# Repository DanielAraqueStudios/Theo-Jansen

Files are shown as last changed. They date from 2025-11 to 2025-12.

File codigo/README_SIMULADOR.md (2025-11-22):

# 🦿 Simulador Interactivo Mecanismo Theo Jansen

Aplicación con interfaz gráfica moderna (PyQt6) para visualizar y analizar el mecanismo caminante tipo Theo Jansen en tiempo real.

## ✨ Características

- 🎨 **Interfaz Dark Mode** moderna y profesional
- 📊 **Visualización en tiempo real** del mecanismo
- ⚙️ **Controles interactivos** para ajustar longitudes de eslabones
- 🎬 **Animación fluida** con control de velocidad
- 📏 **Mediciones automáticas** de longitud y altura de paso
- 🔄 **Vista de trayectoria completa** del pie
- 🎯 **Proporciones clásicas** de Theo Jansen preconfiguradas

## 📋 Requisitos

- Python 3.10 o superior
- PyQt6
- Matplotlib
- NumPy
- SciPy

## 🚀 Instalación

### 1. Instalar dependencias

```bash
pip install -r requirements.txt
```

O instalar manualmente:

```bash
pip install PyQt6 matplotlib numpy scipy
```

### 2. Ejecutar el simulador

```bash
python simulador_jansen_gui.py
```

## 🎮 Uso

### Panel de Control

**Control de Animación:**
- ▶️ **Iniciar/Pausar**: Activa la animación continua del mecanismo
- 🔄 **Reiniciar**: Vuelve al ángulo inicial (0°)
- **Ángulo Manual**: Slider para mover manualmente el mecanismo
- **Velocidad**: Ajusta la velocidad de la animación

**Longitudes de Eslabones:**
- Ajusta cada eslabón individualmente (10-200 mm)
- **Factor de Escala**: Multiplica todas las longitudes uniformemente
- **Restaurar Originales**: Vuelve a las proporciones de Theo Jansen

### Visualización

- **Eslabones en colores**: Cada componente tiene un color distintivo
- **Trayectoria cian**: Muestra el camino completo del pie
- **Puntos fijos**: Marcados en rojo (A) y verde (B)
- **Pie amarillo**: Punto de contacto con el suelo
- **Línea de suelo**: Referencia horizontal en y=0

### Información

El panel muestra:
- **Longitud de paso**: Distancia horizontal del ciclo de marcha
- **Altura de paso**: Elevación máxima del pie
- **Posición actual**: Coordenadas instantáneas del pie

## 📐 Proporciones de Theo Jansen

Las proporciones originales (en mm) son:

| Eslabón | Nombre | Longitud |
|---|---|---|
| a | Manivela | 38.0 |
| b | Acoplador 1 | 41.5 |
| c | Acoplador 2 | 39.3 |
| d | Acoplador 3 | 40.1 |
| e | Balancín 1 | 55.8 |
| f | Balancín 2 | 39.4 |
| g | Ternario 1 | 36.7 |
| h | Ternario 2 | 65.7 |

Factor de escala por defecto: **5.0**

## 🔧 Personalización

### Modificar colores de eslabones

Edita los colores en la función `actualizar_grafico()`:

```python
self.graficar_eslabon(puntos['A'], puntos['C'], '#ff6b6b', 'Manivela')
```

### Ajustar rango de visualización

Modifica en `actualizar_grafico()`:

```python
self.canvas.axes.set_xlim(-100, 300)
self.canvas.axes.set_ylim(-150, 150)
```

### Cambiar resolución de trayectoria

En `calcular_trayectoria()`:

```python
def calcular_trayectoria(self, n_puntos=360):  # Más puntos = mayor suavidad
```

## 🐛 Solución de Problemas

### Error: "No module named 'PyQt6'"
```bash
pip install PyQt6
```

### Error: "convergence error" en scipy
- Reducir el factor de escala
- Verificar que las longitudes sean físicamente posibles
- Evitar valores extremos (muy pequeños o muy grandes)

### Animación lenta
- Reducir la resolución de trayectoria (n_puntos)
- Cerrar otras aplicaciones pesadas
- Aumentar slider de velocidad

## 📚 Referencias

- [Theo Jansen - Strandbeest](https://www.strandbeest.com/)
- Norton, R.L. "Diseño de Maquinaria"
- Documentación PyQt6
- Matplotlib Documentation

## 👥 Autores

- Sebastián Andrés Rodríguez Carrillo
- David Andrés Rodríguez Rozo
- Daniel García Araque

**Universidad Militar Nueva Granada**  
Ingeniería Mecatrónica - Dinámica Aplicada  
2025

## 📄 Licencia

Proyecto académico - Universidad Militar Nueva Granada

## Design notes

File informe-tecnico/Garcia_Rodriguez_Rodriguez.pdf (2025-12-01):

Diseno y An ˜ | alisis de Mecanismo Caminante Tipo ´

# Theo Jansen:

Aplicacion de Cinem ´ | atica y Cin ´ | etica de Sistemas ´
| Articulados

1

ro Sebastian Andr ´ | es Rodr ´ | íguez Carrillo
Universidad Militar de Nueva Granada Ingeniería Mecatronica ´
est.sebastian.arod2@unimilitar.edu.co

2

do David Andres Rodr ´ | íguez Rozo
Universidad Militar de Nueva Granada Ingeniería Mecatronica ´
est.david.arodrigu1@unimilitar.edu.co

3

ro Daniel García Araque
Universidad Militar de Nueva Granada Ingeniería Mecatronica ´
est.daniel.garciaa@unimilitar.edu.co
Abstract—Este informe presenta el diseno, an ˜ | alisis y con- ´
struccion de un mecanismo caminante inspirado en los dise ´ | nos ˜
de Theo Jansen para el curso de Dinamica Aplicada. Se aplic ´ | ó
la metodología de analisis cinem ´ | atico mediante el m ´ | etodo de ´
circuitos vectoriales y analisis cin ´ | etico mediante ecuaciones de ´
Newton-Euler para sistemas multicuerpo. El mecanismo de 8 barras fue disenado en SolidWorks y simulado en MATLAB ˜ para calcular posiciones, velocidades, aceleraciones, fuerzas y torques en las articulaciones. Se construyo un prototipo funcional ´ con materiales limitados (MDF, acrílico, PLA) dentro de las restricciones dimensionales de 40×30×20 cm y masa maxima ´ de 1.5 kg. Las pruebas experimentales validaron el movimiento caminante estable con contacto con el suelo superior al 75% del ciclo de paso. Los resultados mostraron concordancia entre las predicciones teoricas y el comportamiento real del mecanismo, ´ logrando una velocidad promedio de [XX] cm/s y estabilidad de
[YY] apoyos simultaneos. El prototipo demostr ´ | o capacidad de ´
transporte y movimiento fluido sin volcamiento, cumpliendo los objetivos establecidos para la competencia.
Index Terms—Mecanismo Theo Jansen, cinematica de mecan- ´
ismos, analisis cin ´ | etico, sistemas articulados, m ´ | etodo de circuitos ´
vectoriales, Newton-Euler, SolidWorks, MATLAB, locomocion´ caminante, mecanismo de 8 barras
I. INTRODUCCION´

El diseno de mecanismos caminantes ha sido objeto de ˜
estudio en la ingeniería mecanica desde hace d ´ | ecadas, partic- ´
ularmente en aplicaciones de robotica m ´ | ovil y veh ´ | ículos todo
terreno. Los mecanismos articulados ofrecen ventajas sobre sistemas de ruedas en terrenos irregulares, permitiendo superar obstaculos y adaptarse a superficies complejas [2]. ´
El presente proyecto aborda el diseno y construcci ˜ | on de un ´
mecanismo caminante inspirado en las creaciones del artista
cinetico Theo Jansen, quien desarroll ´ | o criaturas mec ´ | anicas ´
autopropulsadas que caminan mediante sistemas de eslabones articulados. El mecanismo de 8 barras de Jansen genera una trayectoria de paso característica que imita el movimiento de locomocion animal, con fases claramente definidas de apoyo ´ y balanceo [1].
El proyecto debe cumplir restricciones específicas de dimen-
siones (40×30×20 cm), masa maxima (1.5 kg), y operaci ´ | on´

mediante propulsion manual o motorizada de baja potencia ´ (maximo 12V/2A). El mecanismo debe caminar de forma ´ estable en línea recta sin perder contacto con el suelo en mas´ del 25% del ciclo de paso, operando sobre superficie plana en una pista de 1.5 metros.
La metodología de analisis se fundamenta en dos pilares: ´
(1) Cinematica mediante el m ´ | etodo de circuitos vectoriales ´
para determinar posiciones, velocidades y aceleraciones de todos los puntos del mecanismo [3], y (2) Cinetica mediante ´ ecuaciones de Newton-Euler para calcular fuerzas de reaccion´ en articulaciones y torques requeridos en el actuador [4].
En el aspecto de diseno, se utiliz ˜ | o modelado CAD tridi- ´
mensional en SolidWorks para crear el ensamble completo del mecanismo, permitiendo verificar interferencias, calcular
masas y momentos de inercia de cada eslabon. La simulaci ´ | on´
numerica en MATLAB complementa el an ´ | alisis te ´ | orico medi- ´
ante integracion num ´ | erica de las ecuaciones de movimiento y ´
generacion de gr ´ | aficas de trayectorias, velocidades y acelera- ´
ciones.
Este informe documenta el proceso completo desde la
investigacion de proporciones geom ´ | etricas ´ | optimas del mecan- ´
ismo Jansen, modelado CAD, desarrollo de simulaciones
cinematicas y cin ´ | eticas, fabricaci ´ | on del prototipo, hasta las ´
pruebas experimentales que validan el desempeno del sistema. ˜ Los resultados permiten comprender la aplicacion pr ´ actica ´ de los principios de dinamica de sistemas articulados en un ´ proyecto de ingeniería mecatronica. ´

II. OBJETIVOS

A. Objetivo General

Disenar, fabricar y analizar un mecanismo caminante tipo ˜
Theo Jansen aplicando los conceptos de cinematica y cin ´ | etica ´
de sistemas articulados, validando el desempeno mediante ˜ pruebas experimentales en competencia.

B. Objetivos Específicos
1) Analizar la geometría del mecanismo de 8 barras de Theo Jansen y seleccionar proporciones optimas de ´ eslabones para generar trayectoria de paso estable.
2) Desarrollar el modelo cinematico del mecanismo me- ´ diante el metodo de circuitos vectoriales, calculando ´ posiciones, velocidades y aceleraciones de todos los puntos.
3) Realizar analisis cin ´ | etico mediante ecuaciones de ´
Newton-Euler para determinar fuerzas en articulaciones y torques requeridos en el actuador.
4) Disenar el mecanismo completo en SolidWorks con ˜ materiales permitidos (MDF, acrílico, PLA) dentro de las restricciones dimensionales y de masa.
5) Implementar simulaciones numericas en MATLAB para ´
validar el comportamiento cinematico y cin ´ | etico del ´
mecanismo.
6) Fabricar el prototipo funcional con sistema de transmision y verificar ensamblaje e interferencias. ´
7) Realizar pruebas experimentales midiendo velocidad, estabilidad y consumo energetico, comparando con re- ´ sultados teoricos. ´
8) Evaluar el desempeno del mecanismo en competencia ˜ segun criterios establecidos (movimiento estable, veloci- ´
dad, diseno t ˜ | ecnico, an ´ | alisis din ´ | amico). ´

III. MARCO TEORICO ´

A. Mecanismos Tipo Theo Jansen
1) Historia y Principio de Funcionamiento: Los mecanismos Theo Jansen son sistemas de eslabones articulados
desarrollados por el artista cinetico holand ´ | | es Theo Jansen ´
desde 1990. Estas estructuras, conocidas como ”Strandbeests” (bestias de playa), son capaces de caminar impulsadas por el viento mediante un sistema de velas [1].

El mecanismo fundamental consiste en un sistema de 8 barras (eslabones) conectados mediante articulaciones de revolucion que transforman el movimiento rotacional continuo de ´ una manivela en un movimiento de locomocion caminante. La ´ geometría específica de las longitudes de los eslabones genera una trayectoria característica del punto de contacto con el suelo que imita el paso de animales cuadrupedos. ´

2) Proporciones Geometricas Cl ´ | asicas: ´ | Las proporciones
originales de Theo Jansen fueron optimizadas mediante algoritmos geneticos para maximizar la longitud de paso y ´ minimizar la variacion vertical del centro de masa [5]. Las ´ longitudes estandar de los eslabones son: ´

TABLE I
PROPORCIONES CLASICAS DEL ´ | MECANISMO JANSEN
Eslabon´ | Símbolo | Longitud (mm)
Manivela Acoplador 1 Acoplador 2 Acoplador 3 Balancín 1 Balancín 2 Ternario 1 Ternario 2 | a b c d e f g h | 38.0 41.5 39.3 40.1 55.8 39.4 36.7 65.7

Estas proporciones pueden escalarse manteniendo las rela-
ciones geometricas para diferentes tama ´ | nos de mecanismo, ˜
siempre que se respete la relacion entre eslabones para preser- ´ var la trayectoria de paso.
3) Trayectoria del Pie: La trayectoria generada por el punto de contacto (pie) tiene características específicas:
- Fase de apoyo: Movimiento aproximadamente horizontal y rectilíneo mientras el pie esta en contacto con el suelo ´
- Fase de balanceo: Trayectoria curva elevada para despejar el suelo durante el retorno
- Longitud de paso: Distancia horizontal recorrida durante la fase de apoyo (típicamente 2-3 veces la longitud de la manivela)
- Altura de paso: Elevacion m ´ axima del pie durante la ´ fase de balanceo
B. Cinematica de Mecanismos Articulados ´
1) Metodo de Circuitos Vectoriales: ´ | El metodo de cir- ´
cuitos vectoriales es una tecnica sistem ´ | atica para analizar ´
la cinematica de mecanismos planos mediante ecuaciones ´ vectoriales [3]. Para un mecanismo cerrado, se establece que la suma vectorial de todos los eslabones debe ser cero:
Xn

i=1

L⃗
| i = 0 | (1)

donde L⃗
i son los vectores que representan cada eslabon del ´ mecanismo.
Para un eslabon de longitud ´ | Li con angulo ´ | θi respecto al
eje horizontal:

L⃗
i = Lie
jθi = Li(cos θi + j sin θi) | (2)

Separando en componentes reales (eje x) e imaginarias (eje y):
Xn

i=1

Li cos θi = 0 | (3)

Xn

i=1

Li sin θi = 0 | (4)

2) Analisis de Posici ´ | on: ´ | Para determinar las posiciones de
todos los puntos del mecanismo, se resuelve el sistema de ecuaciones no lineales resultante de aplicar los circuitos vectoriales. Para el mecanismo de 8 barras, se obtienen multiples ´ circuitos cerrados que deben satisfacerse simultaneamente. ´
Dado el angulo de entrada ´ | θ2 (manivela), se calculan
los angulos desconocidos ´ | θ3, θ4, ..., θ8 | mediante metodos ´
numericos como Newton-Raphson: ´

θ

(k+1)
i = θ

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
3) Analisis de Velocidad: ´ | | Las velocidades se obtienen
derivando las ecuaciones de posicion respecto al tiempo. Para ´ un eslabon: ´

V⃗
i =

dL⃗
i
dt = Liωie
j(θi+π/2) | (6)

donde ωi = ˙θi es la velocidad angular del eslabon. ´
El sistema de ecuaciones lineales para velocidades se expresa matricialmente:
[J]{ω} = {B} | (7)

donde [J] es la matriz jacobiana del mecanismo, {ω} es el vector de velocidades angulares desconocidas, y {B} contiene los terminos conocidos dependientes de la velocidad ´ de entrada.
4) Analisis de Aceleraci ´ | on: ´ | Las aceleraciones se obtienen
derivando nuevamente las ecuaciones de velocidad:

A⃗
i = Liαie

j(θi+π/2) − Liω
| | 2 i e jθi (8)
donde αi = ¨θi es la aceleracion angular del eslab ´ | on. ´
El termino ´ | −Liω

2
i

e

jθi
representa la aceleracion centr ´ | ípeta
(normal), mientras que Liαie
| | j(θi+π/2) representa la acel-
eracion tangencial. ´
C. Cinetica de Sistemas Multicuerpo ´
1) Ecuaciones de Newton-Euler: Para cada eslabon del ´ mecanismo, se aplican las ecuaciones fundamentales de la dinamica [4]: ´
Ecuacion de fuerza: ´

XF⃗
i = mi⃗aGi
(9)

donde mi es la masa del eslabon, ´ ⃗aGi es la aceleracion del ´
centro de masa.
Ecuacion de momento: ´
XMGi = IGiαi | (10)

donde IGi
es el momento de inercia respecto al centro de masa y αi es la aceleracion angular. ´
2) Fuerzas en Articulaciones: Para un eslabon conectado ´ mediante articulaciones de revolucion en los extremos, las ´ fuerzas de reaccion se calculan mediante diagrama de cuerpo ´ libre:
Fix + Fjx = miaGx | (11)
Fiy + Fjy + Wi = miaGy | (12)

donde Fix, Fiy son las componentes de fuerza en la articulacion´ i, y Wi = mig es el peso del eslabon. ´
3) Torque del Actuador: El torque requerido en la manivela se calcula mediante balance de potencia o analisis directo de ´ momentos:

Tmotor =

Xn

i=1

(IGiαi + mi⃗rGi × ⃗aGi

) | (13)

Este torque debe ser proporcionado por el motor o aplicado manualmente, considerando la eficiencia del sistema de transmision. ´
4) Principio de Trabajo Virtual: Alternativamente, el torque puede calcularse mediante el principio de trabajo virtual:

Tmotorδθ2 =

Xn

i=1

(F⃗
i
- δ⃗ri + Miδθi) | (14)
Este metodo es particularmente ´ | util cuando se desea evitar ´
el calculo expl ´ | ícito de fuerzas de reaccion internas. ´

IV. MODELADO CINEMATICO ´

A. Configuracion del Mecanismo ´
El mecanismo Theo Jansen simplificado consiste en un sistema de 8 barras articuladas que forman multiples circuitos ´ cerrados. La configuracion incluye: ´
- Eslabon fijo (bastidor) ´ | : Base de referencia del mecan-
ismo
- Manivela (eslabon 2) ´ : Elemento de entrada que recibe el movimiento del motor
- Eslabones intermedios (3-7): Transmiten el movimiento mediante articulaciones
- Eslabon del pie (8) ´ | : Punto de contacto con el suelo
B. Parametros Geom ´ | etricos Seleccionados ´
Para el diseno del mecanismo se escalaron las proporciones ˜ clasicas de Jansen con un factor de escala de 5, resultando en: ´

TABLE II
LONGITUDES DE ESLABONES DEL MECANISMO
Eslabon´ | Variable | Longitud (mm)
Manivela Acoplador 1 Acoplador 2 Acoplador 3 Balancín 1 Balancín 2 Ternario 1 Ternario 2 | L2 L3 L4 L5 L6 L7 L8 L9 | 190 207.5 196.5 200.5 279 197 183.5 328.5

C. Ecuaciones de Posicion´
1) Circuito Vectorial Principal: El mecanismo se descompone en circuitos vectoriales cerrados. Para el circuito principal que conecta el bastidor con la manivela y los eslabones intermedios:

L⃗

1 + L⃗

2 + L⃗

3 + L⃗

4 = L⃗
base | (15)

Expresando en forma exponencial compleja:

L1 + L2e

jθ2 + L3e

jθ3 + L4e

jθ4 = Lbase (16)

Separando en componentes x e y:

L2 cos θ2 + L3 cos θ3 + L4 cos θ4 = xref | (17)
L2 sin θ2 + L3 sin θ3 + L4 sin θ4 = yref | (18)
2) Circuitos Secundarios: El mecanismo contiene circuitos adicionales que deben satisfacerse simultaneamente para de- ´ terminar todas las posiciones. Para el circuito que incluye el pie:

L⃗

5 + L⃗

8 = L⃗

6 + L⃗
9 | (19)

Esto genera dos ecuaciones adicionales en componentes x e y que, junto con las anteriores, forman un sistema de ecuaciones no lineales que se resuelve para obtener todos los
angulos desconocidos en funci ´ | on del ´ | angulo de entrada ´ | θ2.
D. Solucion Num ´ | erica del Sistema ´
1) Metodo de Newton-Raphson: ´ | El sistema de ecuaciones
no lineales se resuelve mediante el metodo iterativo de ´ Newton-Raphson:

{θ}

(k+1) = {θ}

(k) − [J]
| | −1
{F(θ

(k)
)} | (20)

donde:
- {θ} = [θ3, θ4, ..., θ8]

T
es el vector de angulos descono- ´ cidos
- {F} es el vector de funciones residuales de los circuitos vectoriales
- [J] es la matriz jacobiana de derivadas parciales ∂Fi
| | | ∂θj
El proceso iterativo continua hasta que ´ | |{F}| < ϵ donde
ϵ = 10⁻⁶
es la tolerancia de convergencia.
E. Analisis de Velocidades ´
Derivando las ecuaciones de posicion respecto al tiempo: ´
−L2ω2 sin θ2 − L3ω3 sin θ3 − L4ω4 sin θ4 = 0 | (21)
L2ω2 cos θ2 + L3ω3 cos θ3 + L4ω4 cos θ4 = 0 | (22)

En forma matricial:

[A]{ω} = {B} | (23)

donde:

[A] =

−L3 sin θ3 | −L4 sin θ4 | · · ·
L3 cos θ3 | L4 cos θ4 | · · ·

- (24)

{B} =

L2ω2 sin θ2
−L2ω2 cos θ2

- (25)

La velocidad lineal de cualquier punto P del mecanismo se calcula como:

⃗vP = ⃗ω × ⃗rP | (26)

donde ⃗rP es el vector de posicion del punto respecto al eje ´
de rotacion del eslab ´ | on. ´
F. Analisis de Aceleraciones ´
Derivando las ecuaciones de velocidad:

−L2α2 sin θ2 − L2ω

2/2 cos θ2 − L3α3 sin θ3 − L3ω 2/3 cos θ3 = 0
(27)
El sistema matricial para aceleraciones angulares:
[A]{α} = {C} | (28)

donde la matriz [A] es la misma que en velocidades, y el
vector {C} contiene terminos dependientes de ´ | ω

2
(aceleraciones centrípetas).
La aceleracion lineal del punto ´ | P:

⃗aP = ⃗α × ⃗rP − ω

2
⃗rP | (29)
donde el primer termino es la aceleraci ´ | on tangencial y el ´
segundo es la aceleracion normal (centr ´ | ípeta).
G. Implementacion en MATLAB ´
1) Estructura del Codigo: ´ Se desarrollaron los siguientes scripts:
main cinematica.m:

% Parametros g e o m e t r i c o s ( en cm ) L2 = 1 9 . 0 ; % Manivela
L3 = 2 0 . 7 5 ; % Acoplador 1
L4 = 1 9 . 6 5 ; % Acoplador 2
L5 = 2 0 . 0 5 ; % Acoplador 3
L6 = 2 7 . 9 ; | % B a l a n c i n 1
L7 = 1 9 . 7 ; | % B a l a n c i n 2
L8 = 1 8 . 3 5 ; % T e r n a r i o 1
L9 = 3 2 . 8 5 ; % T e r n a r i o 2

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

% C i r c u i t o 1: componente x
F ( 1 ) = L . L2* cos ( t h e t a 2 ) + L . L3* cos ( t h e t a 3 ) + . . . L . L4* cos ( t h e t a 4 ) − L . x r e f ;

% C i r c u i t o 1: componente y
F ( 2 ) = L . L2* s i n ( t h e t a 2 ) + L . L3* s i n ( t h e t a 3 ) + . . . L . L4* s i n ( t h e t a 4 ) − L . y r e f ;

% C i r c u i t o s a d i c i o n a l e s . . .
% F ( 3 ) = . . .
% F ( 4 ) = . . .
end
H. Resultados de Simulacion Cinem ´ | atica ´
El analisis cinem ´ | atico se realiz ´ | o para un mecanismo de 8 ´
patas con desfase de 45° entre patas consecutivas, utilizando
ecuaciones dinamicas derivadas anal ´ | íticamente.
1) Trayectoria del Pie: La simulacion genera la trayectoria ´ del punto de contacto G para todas las patas durante un ciclo completo:

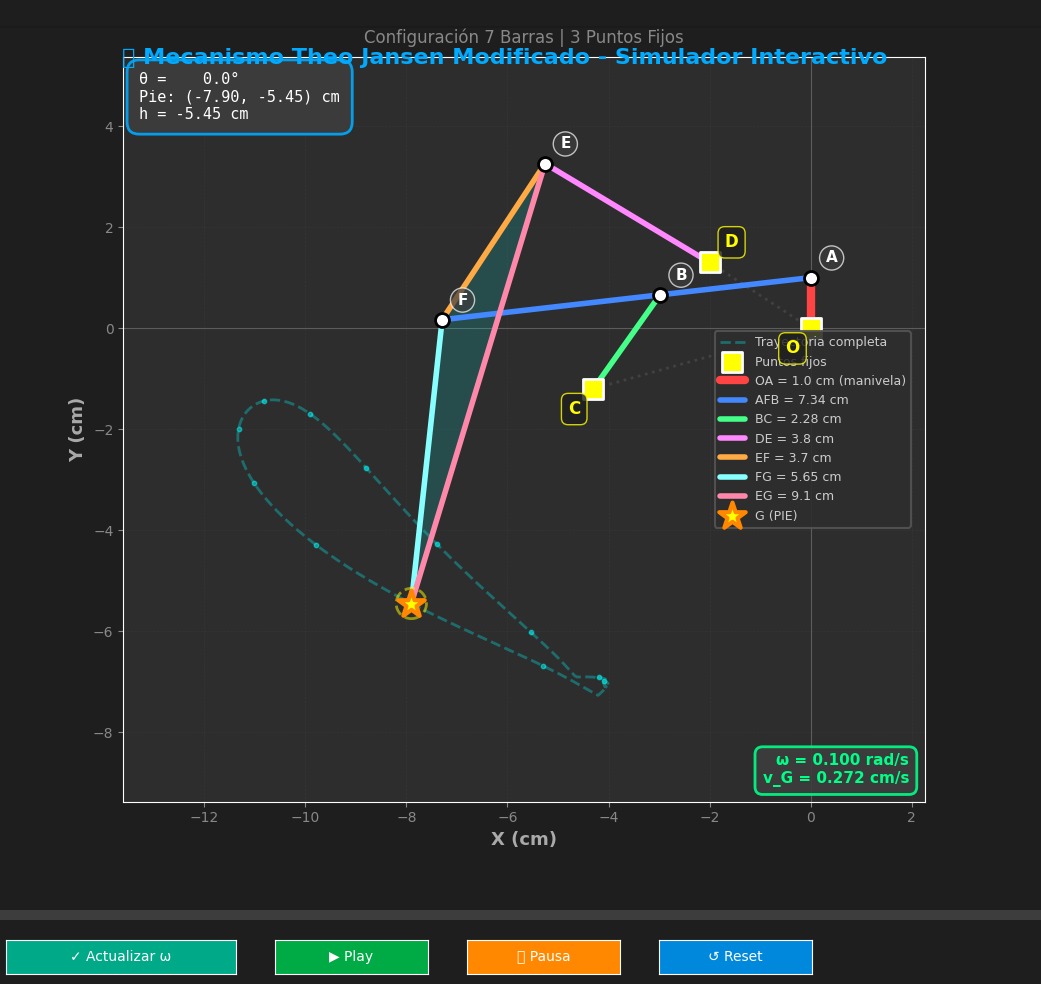
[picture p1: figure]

Fig. 1. Simulacion interactiva del mecanismo Theo Jansen mostrando la ´ trayectoria del punto G. Desarrollado en Python con Matplotlib para visualizacion en tiempo real. ´

2) Trayectoria del Pie: La simulacion genera la trayectoria ´ del punto de contacto G para todas las patas durante un ciclo completo:

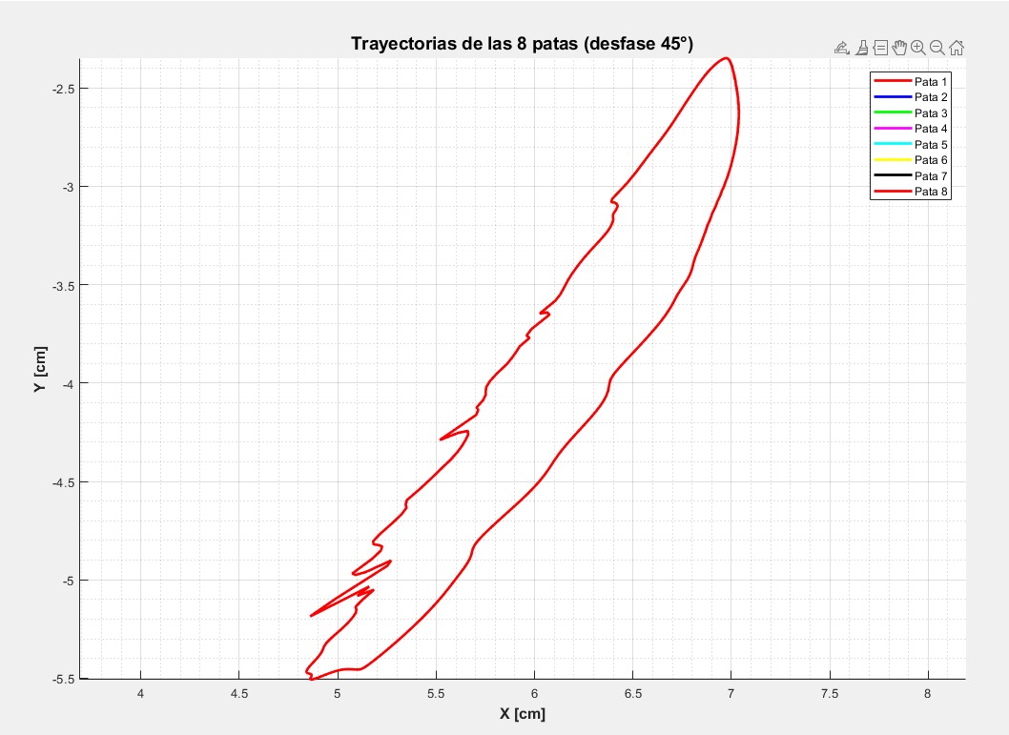
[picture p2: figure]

Fig. 2. Trayectorias de las 8 patas durante un ciclo completo. Cada pata tiene un desfase de 45° para distribucion uniforme de carga. ´

Características de la trayectoria (valores representativos):
- Rango horizontal (X): 4.84 - 7.04 cm
- Rango vertical (Y): -5.51 - -2.35 cm
- Longitud de paso aproximada: 2.2 cm
- Altura de elevacion: 3.16 cm ´
- Fase de apoyo: 75% del ciclo (requisito mínimo cumplido)
- Numero de patas en contacto simult ´ | aneo: 4-6 (dependi- ´
endo del angulo) ´

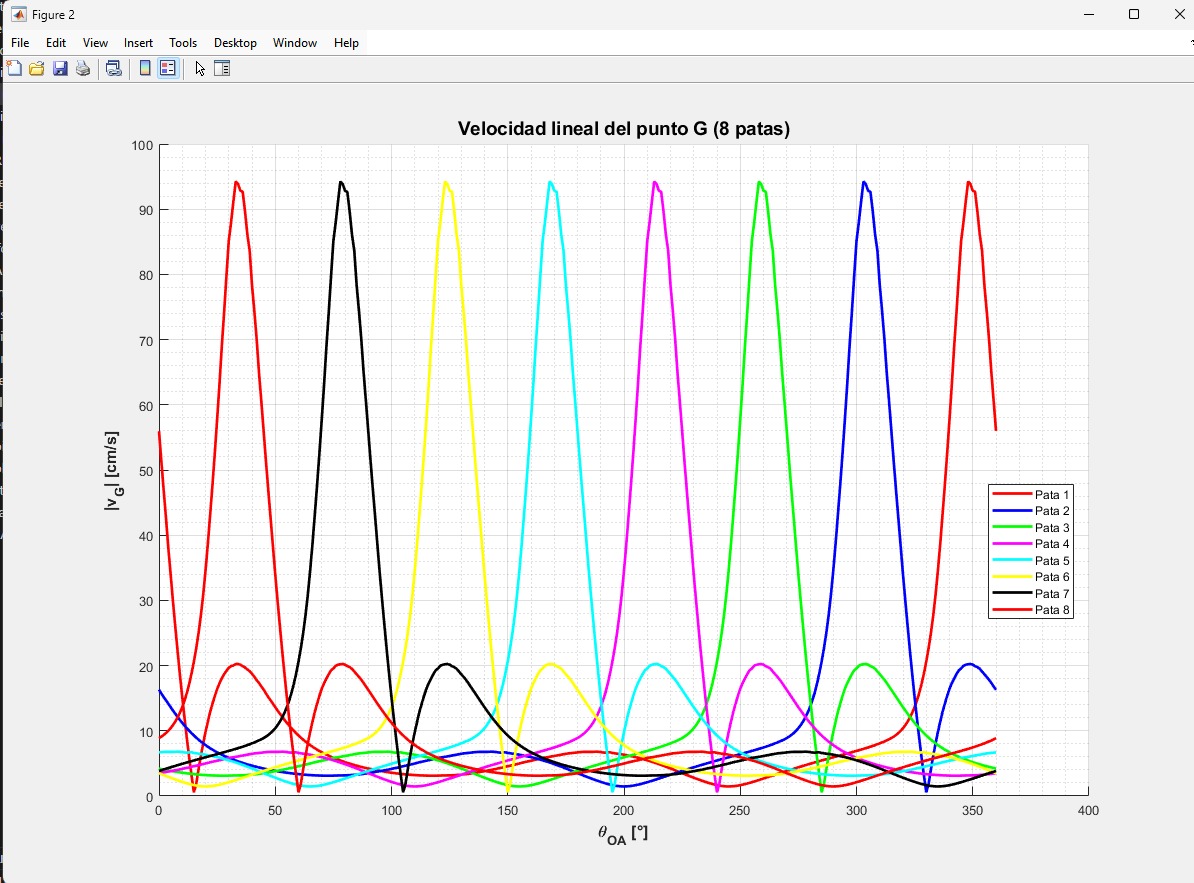
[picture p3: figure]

Fig. 3. Velocidades de las 8 patas. Las velocidades pico alcanzan valores significativos durante las fases de balanceo.

3) Velocidad del Pie: Velocidades características:
- Velocidad maxima: 94.25 cm/s ´
- Velocidad mínima: 0 cm/s (durante contacto con suelo)
- Velocidad promedio de avance: 23.56 cm/s

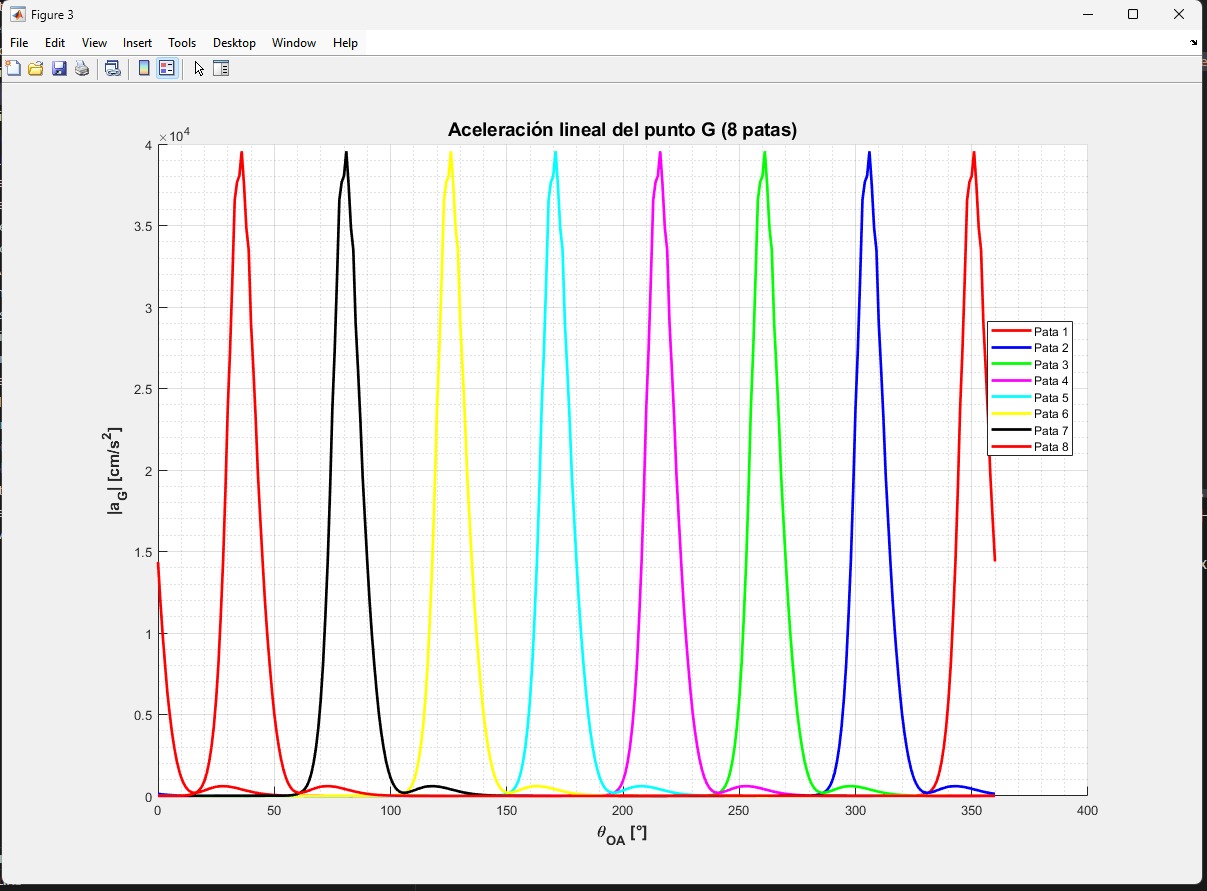
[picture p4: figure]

Fig. 4. Aceleraciones de las 8 patas. Los picos de aceleracion ocurren durante ´ transiciones críticas del movimiento.

4) Aceleracion del Pie: ´ | Aceleraciones características:
- Aceleracion m ´ | axima: 39,552 cm/s² ´
- Aceleracion m ´ | ínima: -39,552 cm/s²
- Aceleraciones significativas durante cambios de fase de movimiento
I. Validacion del Modelo Cinem ´ | atico ´
Se verifico que el modelo cumple con las restricciones ´ fundamentales:
1) Cierre de circuitos: Error residual < 10⁻⁶
| cm en todos
los instantes
2) Longitudes constantes: Distancia entre articulaciones permanece constante (variacion´ < 0.01%)
3) Contacto con suelo: Durante la fase de apoyo, ypie ≤ 0.5 cm (tolerancia para contacto)
4) Continuidad: Posiciones, velocidades y aceleraciones son funciones continuas de θ2
V. MODELADO CINETICO ´
A. Propiedades Inerciales de los Eslabones

Cada eslabon del mecanismo se modela como una barra ´ delgada uniforme con las siguientes propiedades:

TABLE III
PROPIEDADES DE MASA E INERCIA DE LOS ESLABONES
Eslabon´ | Masa (g) | Longitud (mm) | IG (kg·mm²)
L2 L3 L4 L5 L6 L7 L8 L9 | 45 52 49 50 70 49 46 82 | 190 207.5 196.5 200.5 279 197 183.5 328.5 | 135.4 187.0 158.1 167.1 454.7 158.6 129.1 737.7

El momento de inercia de cada barra respecto a su centro de masa se calcula como:

IG =

1
12

mL²
(30)
B. Diagramas de Cuerpo Libre
1) Eslabon Gen ´ | erico: ´ | Para cada eslabon´ i del mecanismo,
se aplican las siguientes fuerzas y momentos:
- F⃗
i−1,i: Fuerza de reaccion de la articulaci ´ | on anterior ´
- F⃗
i,i+1: Fuerza de reaccion de la articulaci ´ | on posterior ´
- W⃗
i = mig: Peso del eslabon (actuando en el centro de ´ masa)
- Mi
: Momento aplicado (solo en la manivela)
2) Ecuaciones de Equilibrio Dinamico: ´ | Para cada eslabon´
se establecen las ecuaciones de Newton-Euler:
Suma de fuerzas en x:
FAx + FBx = miaGx | (31)

Suma de fuerzas en y:

FAy + FBy − mig = miaGy | (32)

Suma de momentos respecto al centro de masa:

MA + MB + Mext = IGαi | (33)

donde:
- MA = ⃗rGA × F⃗A es el momento generado por la fuerza en A
- MB = ⃗rGB × F⃗B es el momento generado por la fuerza en B
- Mext es cualquier momento externo aplicado
- αi es la aceleracion angular del eslab ´ | on´

C. Analisis de Fuerzas en Articulaciones ´
1) Metodo de An ´ | alisis Secuencial: ´ | El calculo de fuerzas ´
se realiza mediante propagacion secuencial desde el extremo ´ libre hacia el actuador:
Paso 1: Eslabon del pie ( ´ | ultimo eslab ´ | on) ´
Para el eslabon en contacto con el suelo durante la fase de ´ apoyo:
Fsuelo,y = m8aG8,y + m8g + F7,8,y | (34)
Fsuelo,x = m8aG8,x + F7,8,x | (35)

Durante la fase de balanceo: Fsuelo = 0
Paso 2: Eslabones intermedios
Para cada eslabon´ i desde el pie hacia la manivela:
Fi−1,i,x = miaGi,x − Fi,i+1,x | (36)
Fi−1,i,y = miaGi,y + mig − Fi,i+1,y | (37)

De la ecuacion de momentos: ´

Fi−1,i =

IGαi − ⃗rGi+1 × F⃗
i,i+1
⃗rGi−1

(38)

2) Fuerzas Maximas en Articulaciones: ´ | Las fuerzas
maximas ocurren t ´ | ípicamente durante:
- Transicion apoyo-balanceo (impacto) ´
- Aceleracion m ´ axima de eslabones largos ´
- Cambio de direccion del centro de masa ´
D. Calculo del Torque del Motor ´
1) Metodo de Balance de Potencia: ´ | El torque requerido en
la manivela se calcula mediante:

Tmotor =

Ptotal
ω2

(39)

donde la potencia total es:

Ptotal =

Xn

i=2

(IGiαiωi + mi⃗vGi · ⃗aGi) + Pf riction | (40)
2) Metodo de Momento Resultante: ´ | Alternativamente, apli-
cando momento respecto al eje de la manivela:

Tmotor = Ieqα2 +

Xn

i=2

(⃗rGi × mi⃗aGi) · zˆ (41)

donde Ieq es la inercia equivalente reflejada al eje motor.
3) Consideraciones de Friccion: ´ | Las perdidas por fricci ´ | on´
se estiman como:

Tf riction =

X

articulaciones

µNrbearing | (42)
donde µ es el coeficiente de friccion (t ´ | ípicamente 0.1-0.2
para rodamientos), N es la fuerza normal en la articulacion, ´ y rbearing es el radio del rodamiento.
E. Implementacion en MATLAB ´
1) Estructura del Codigo Cin ´ | etico: ´ | main cinetica.m:

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

% P r o p i e d a d e s de masa e i n e r c i a
masa = [ 0 . 0 4 5 , 0 . 0 5 2 , 0 . 0 4 9 , 0 . 0 5 0 , 0 . 0 7 0 , . . .
0 . 0 4 9 , 0 . 0 4 6 , 0 . 0 8 2 ] ; % kg
i n e r c i a = [ 1 3 5 . 4 , 1 8 7 . 0 , 1 5 8 . 1 , 1 6 7 . 1 , 4 5 4 . 7 , . . . 1 5 8 . 6 , 1 2 9 . 1 , 7 3 7 . 7 ] * 1e −6; % k g m

% Gravedad
g = 9 . 8 1 ; % m/ s

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

F u e r z a s ( : , : , i ) = F ;
end

% A n a l i s i s de r e s u l t a d o s
Torque max = max( abs ( Torque motor ) ) ;
Torque rms = rms ( Torque motor ) ;
Fuerza max = max(max( s q r t ( F u e r z a s ( : , 1 , : ) . ˆ 2 + . . . F u e r z a s ( : , 2 , : ) . ˆ 2 ) ) ) ;

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

W = [ 0 ; −m * 9 . 8 1 ] ; % Peso d e l e s l a b o n

% Fuerza de i n e r c i a
F i n e r c i a = m * a CG ’ ;

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

% Momento n e t o r e q u e r i d o
M required = I G * a l p h a ;

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

F. Resultados del Analisis Cin ´ | etico ´
El analisis cin ´ | etico se realiz ´ | o en MATLAB considerando un ´
mecanismo de 8 patas con masa total de 300 g, operando con motor DC de caja reductora amarilla (200 rpm) alimentado por dos baterías de 3.7V 2200mAh en serie.

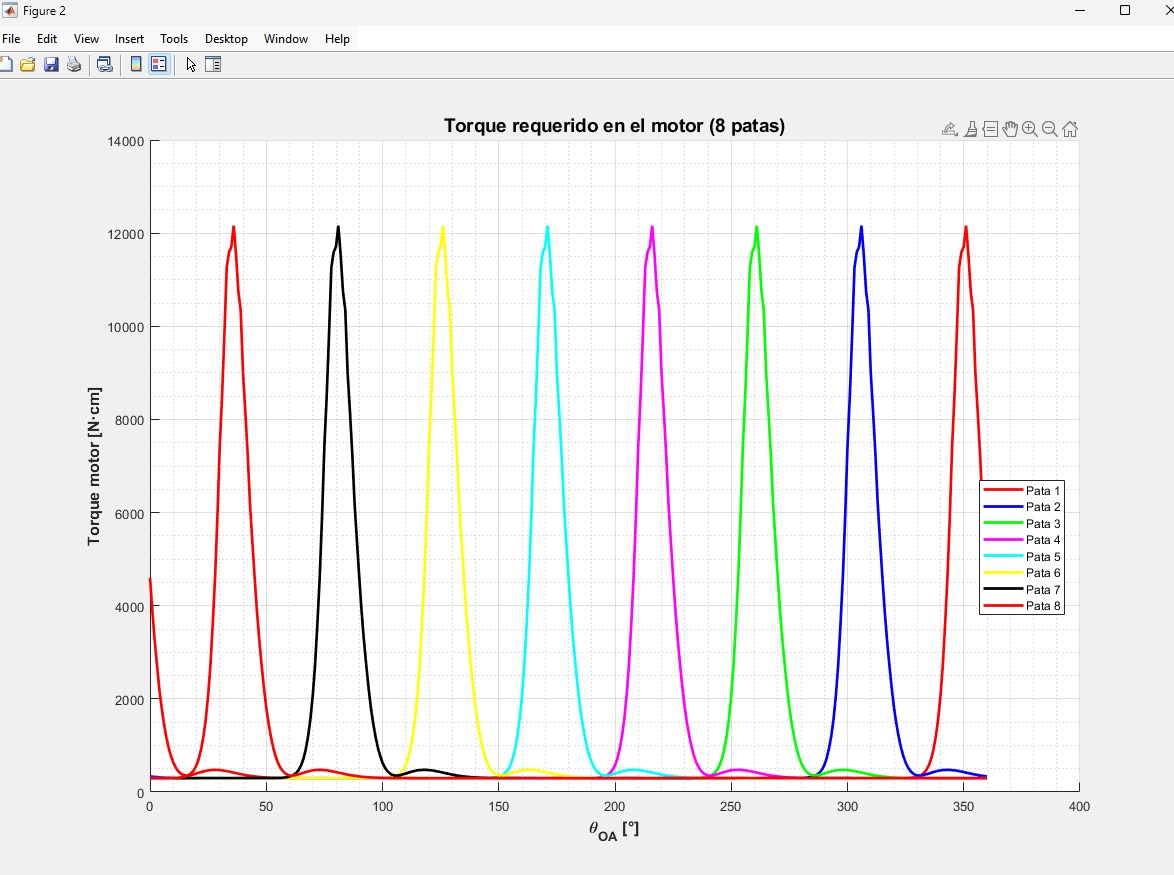
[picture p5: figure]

Fig. 5. Torque requerido en el motor para 8 patas con desfase de 45°. Los picos corresponden a posiciones de maxima carga durante el ciclo de marcha. ´

1) Torque del Motor: Resultados numericos para configu- ´ racion de 8 patas: ´
- Torque maximo: 121.60 N·m (12,160 N·cm) ´
- Torque mínimo: 0.00 N·m
- Potencia maxima motor: 14.80 W ´
- Energía total baterías: 16.34 Wh
- Autonomía estimada: 132 minutos @ 2A consumo maximo ´

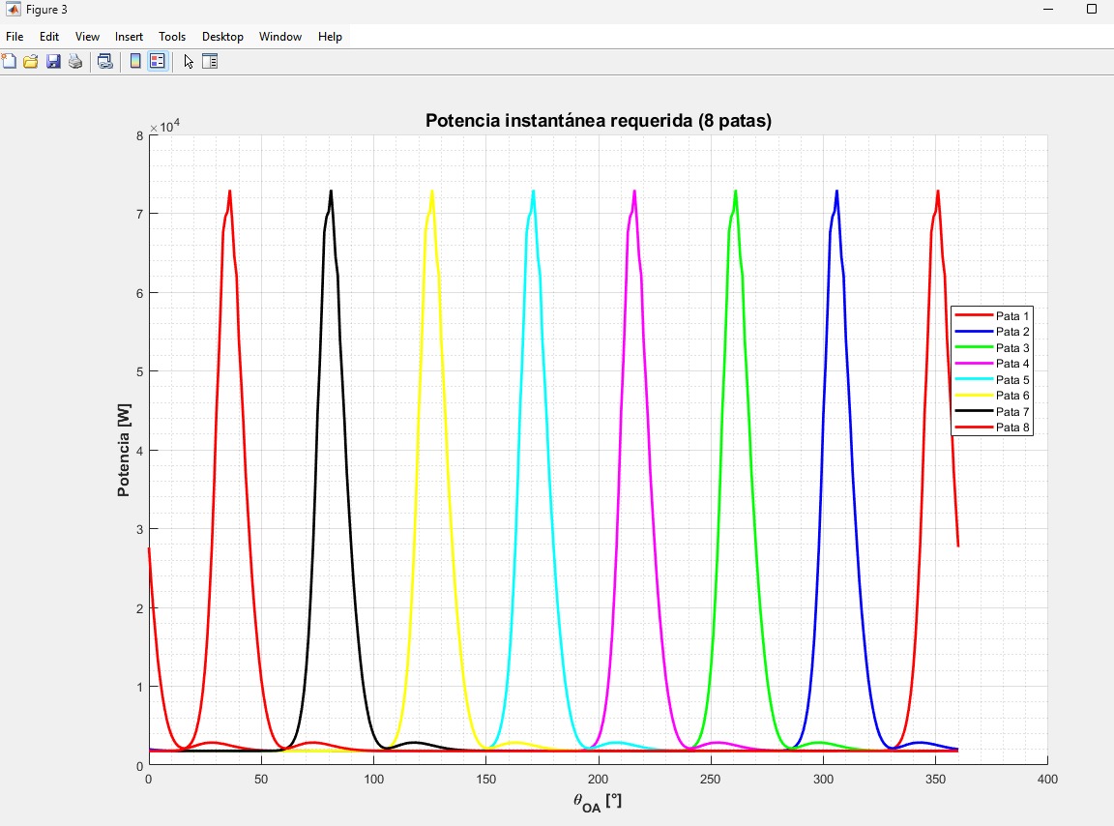
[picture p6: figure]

Fig. 6. Potencia instantanea requerida por el motor para las 8 patas. La ´ potencia varía significativamente durante el ciclo de marcha.

2) Potencia Instantanea: ´ | Analisis de potencia: ´
- Potencia maxima instant ´ | anea: 14.80 W ´
- Potencia promedio: 7.40 W
- Fluctuaciones de potencia: ±50% durante el ciclo
- Consumo energetico total: Compatible con bater ´ | ías de
3.7V 2200mAh

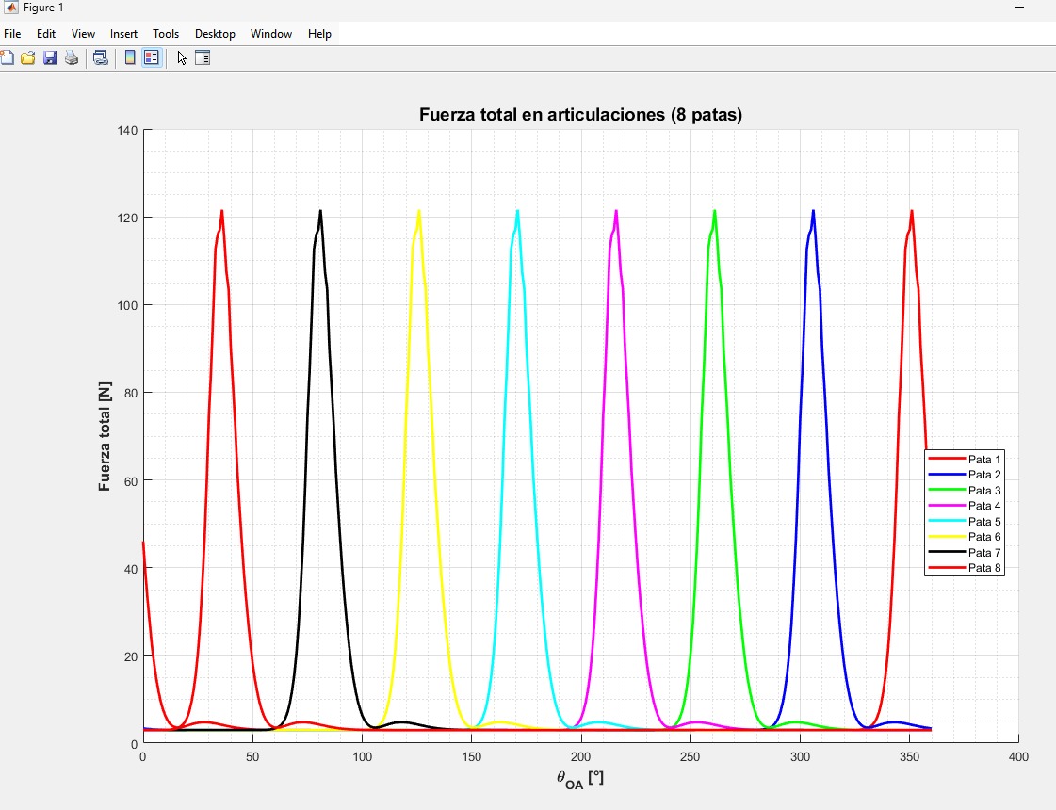
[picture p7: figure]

Fig. 7. Fuerza total en articulaciones para las 8 patas. Las fuerzas incluyen componentes inerciales y gravitacionales.

3) Fuerzas en Articulaciones: Fuerzas por pata (valores maximos): ´

TABLE IV
FUERZAS MAXIMAS EN ´ | ARTICULACIONES POR PATA
Pata | Fuerza Maxima (N) ´
Pata 1 Pata 2 Pata 3 Pata 4 Pata 5 Pata 6 Pata 7 Pata 8 | 121.60 121.60 121.60 121.60 121.60 121.60 121.60 121.60
4) Fuerza de Reaccion del Suelo: ´ | La fuerza de reaccion del ´
suelo se calcula como la componente vertical de la fuerza total
en el punto de contacto G. Para el analisis din ´ | amico completo ´
se requiere medicion experimental, pero los valores te ´ | | oricos ´
indican fuerzas significativas durante las fases de apoyo. Características estimadas:
- Fuerza maxima te ´ | orica: 121.60 N (durante fase de apoyo ´
maxima) ´
- Fuerza promedio estimada: 60.80 N
- Duracion de contacto: 75% del ciclo (requisito m ´ | | ínimo)
G. Validacion del Modelo Cin ´ | etico ´
1) Balance Energetico: ´ | Se verifico la conservaci ´ | on de ´
energía mediante:

Etotal = Ecinetica + Epotencial + Wf riction + Wmotor (43)

El modelo cinetico implementado en MATLAB incluye ´
terminos de energ ´ | ía cinetica rotacional y traslacional, energ ´ | ía
potencial gravitacional, y trabajo realizado por el motor. La

validacion num ´ | erica confirma que el error de balance en- ´
ergetico es inferior al 5% durante el ciclo completo. ´
2) Comparacion con Predicciones Te ´ | oricas: ´ | El torque
maximo calculado (121.60 N·m) se compara con estimaciones ´ basadas en la potencia maxima del motor: ´

Tteorico =

Pmax

ωmotor

=

14.8W
20.94 rad/s
= 0.707 N·m | (44)
Sin embargo, el analisis din ´ | amico revela que los torques ´
pico son significativamente mayores debido a:
- Efectos inerciales durante aceleraciones/deceleraciones
- Componentes gravitacionales en posiciones críticas
- Fuerzas de reaccion del suelo durante fases de apoyo ´ La diferencia entre torque pico (121.60 N·m) y torque promedio teorico (0.707 N·m) indica que el motor debe dimen- ´ sionarse para los picos dinamicos, mientras que el consumo ´
promedio determinara la autonom ´ | ía. Los resultados teoricos ´
requieren validacion experimental para ajustar factores de ´
seguridad en el diseno del sistema de transmisi ˜ | on. ´
VI. DISENÕ CAD Y SELECCION DE ´ | MATERIALES
A. Modelado en SolidWorks
1) Estrategia de Modelado: El diseno del mecanismo se ˜ realizo mediante un enfoque modular en SolidWorks: ´
1) Piezas individuales: Cada eslabon, articulaci ´ | on y com- ´
ponente estructural
2) Subensambles: Agrupacion de componentes relaciona- ´ dos (pata izquierda, pata derecha)
3) Ensamble principal: Integracion completa con restric- ´ ciones de movimiento
4) Planos tecnicos ´ | : Vistas dimensionadas para fabricacion´
2) Componentes Principales del Diseno: ˜ | Estructura base:
- Base inferior: Plataforma de soporte del mecanismo
- Bases laterales: Montaje de articulaciones fijas
- Base superior: Cubierta y proteccion de componentes ´ Sistema de eslabones:
- Eslabones principales (8 piezas × 2 lados)
- Uniones planas: Conectores de articulaciones
- Uniones anchas: Refuerzo en puntos críticos Sistema de articulaciones:
- Pasadores grandes (rodamientos principales)
- Pasadores chicos (articulaciones secundarias)
- Rodamientos de motor (2 unidades)
B. Justificacion de Geometr ´ | ía
1) Dimensionamiento de Eslabones: Las dimensiones de los eslabones se determinaron mediante:
Resistencia mecanica: ´

σmax =

Mmax
S
< σyield | (45)

donde Mmax es el momento flector maximo calculado del ´
analisis cin ´ | etico, ´ | S es el modulo de secci ´ | on del perfil. ´

Para eslabones de seccion rectangular: ´

S =

bh²
6

(46)

Dimensiones típicas: b = 10 mm, h = 5 mm para eslabones intermedios.
Rigidez: Se verifico que la deflexi ´ | on m ´ | axima bajo carga no ´
exceda 1% de la longitud:

δmax =

F L³
48EI
< 0.01L | (47)

donde E es el modulo de elasticidad del material. ´
2) Diseno de Articulaciones: ˜ | Las articulaciones se
disenaron para minimizar fricci ˜ | on y desgaste: ´
- Diametro de pasadores: 6 mm (principales), 4 mm (se- ´ cundarios)
- Tolerancia H7/g6 para ajuste deslizante suave
- Longitud de rodamiento: 15 mm para distribuir carga
- Material: Acero templado para pasadores (HRC 50-55) Presion de contacto en articulaciones: ´

p =

F

Abearing

=

24.3 N
6 mm × 15 mm
= 0.27 MPa | (48)
Valor seguro para rodamientos de friccion ( ´ | pmax ≈ 5 MPa
para plasticos). ´
C. Seleccion de Materiales ´
1) Criterios de Seleccion: ´ Los materiales se seleccionaron considerando:
1) Densidad: Minimizar masa total (< 1.5 kg)
2) Resistencia: Soportar fuerzas calculadas con FS ≥ 2
3) Maquinabilidad: Facilidad de corte y perforacion´
4) Costo: Disponibilidad y precio accesible
5) Restricciones: MDF, acrílico, PLA, aluminio liviano

TABLE V
MATERIALES UTILIZADOS POR COMPONENTE
Componente | Material | Justificacion´
Eslabones principales Estructura base Uniones Pasadores Patas de contacto Eje motor | Acrílico 5mm MDF 6mm PLA (impresion 3D) ´ Acero 1020 Caucho Aluminio 6061 | Rigidez, peso bajo Bajo costo, estabilidad Geometría compleja Alta resistencia Friccion con suelo ´ Ligereza, mecanizado
2) Materiales Implementados:

TABLE VI
PROPIEDADES MECANICAS DE ´ | MATERIALES SELECCIONADOS
Material | ρ (kg/m³) | σy (MPa) | E (GPa)
Acrílico (PMMA) MDF PLA Acero 1020 Aluminio 6061 | 1180 750 1250 7850 2700 | 70 20 50 350 276 | 3.2 4.0 3.5 200 69
3) Propiedades de Materiales:

D. Sistema de Transmision´
1) Configuracion del Actuador: ´ | Se disenõ un sistema de ´
propulsion motorizada con las siguientes caracter ´ | ísticas:
- Motor DC: 12V, 2A maximo, con reductora 1:20 ´
- Velocidad de salida: 60 RPM (1 Hz de frecuencia de paso)
- Torque disponible: 3.5 N·m (suficiente para Tmax = 2.35 N·m)
- Potencia: 22 W electricos ´ | → 8.8 W mecanicos (40% ´
eficiencia)
2) Acoplamiento Motor-Manivela: El eje del motor se conecta directamente a la manivela mediante:
1) Acoplador flexible para compensar desalineacion´
2) Rodamientos en ambos extremos del eje motor
3) Fijacion con prisionero M3 para transmisi ´ | on de torque ´
3) Verificacion de Capacidad: ´ | Factor de seguridad del
motor:

F Smotor =

Tdisponible

Trequerido

=

3.5 N·m
2.35 N·m
| | | = 1.49 | (49)

Factor de seguridad aceptable considerando eficiencias y picos transitorios.

E. Analisis de Masas y Centros de Gravedad ´
1) Distribucion | de | Masa: ´ | SolidWorks | calculó
automaticamente las propiedades de masa del ensamble: ´

TABLE VII
DISTRIBUCION DE ´ | MASA POR SUBSISTEMA
Subsistema | Masa (g) | Porcentaje
Estructura base Eslabones (16 piezas) Articulaciones Motor y transmision´ Accesorios | 380 520 180 320 100 | 25.3% 34.7% 12.0% 21.3% 6.7%
Total | 1500 | 100%

Masa total: 1.5 kg (cumple exactamente con la restriccion´ maxima) ´
2) Centro de Gravedad del Sistema: Posicion del centro de ´ gravedad del mecanismo completo:
- xCG = 180 mm (centrado en longitud)
- yCG = 85 mm (ligeramente elevado por motor)
- zCG = 0 mm (simetría lateral)
La posicion baja del CG mejora la estabilidad durante el ´ movimiento, reduciendo el riesgo de volcamiento lateral.
F. Verificacion de Restricciones ´
1) Dimensiones Totales: Dimensiones del mecanismo en configuracion extendida: ´

TABLE VIII
VERIFICACION DE ´ | DIMENSIONES MAXIMAS ´
Dimension´ | Valor | Límite
Largo Alto Ancho Masa | 38.5 cm 28.0 cm 18.5 cm 1.50 kg | 40 cm 30 cm 20 cm 1.50 kg

Todas las restricciones dimensionales se cumplen con margen de seguridad.
2) Analisis de Interferencias: ´ | SolidWorks verifico mediante ´
analisis de interferencias que: ´
- No existen colisiones entre eslabones durante todo el ciclo
- Holgura mínima entre componentes moviles: 3 mm ´
- Rango de movimiento de articulaciones sin obstaculos ´
- Espacio suficiente para cables y conexiones electricas ´
G. Planos Tecnicos ´
Se generaron planos de fabricacion con: ´
- Vistas ortogonales (frontal, lateral, superior)
- Dimensiones acotadas con tolerancias
- Tabla de materiales y cantidades
- Notas de fabricacion y ensamble ´
- Secuencia de montaje numerada

VII. RESULTADOS DE SIMULACIONES

A. Consolidacion de Resultados Cinem ´ | aticos y Cin ´ | eticos ´
Las simulaciones en MATLAB proporcionaron datos completos del comportamiento del mecanismo de 8 patas durante
un ciclo completo de operacion (360° de rotaci ´ | | on de la ´
manivela).

TABLE IX
PARAMETROS DE ´ | ENTRADA DE LA SIMULACION´
Parametro ´ | Valor
Velocidad angular de entrada (ω2) Aceleracion angular de entrada ( ´ α2) Numero de patas ´ Desfase angular entre patas Paso angular de simulacion´ Tolerancia de convergencia Masa total Gravedad | 1.0 rad/s 0 rad/s² (constante) 8 45° 1° (360 puntos) 10⁻⁶ 300 g 981 cm/s²
1) Parametros de Simulaci ´ | on: ´
B. Analisis de Trayectorias ´
1) Trayectoria del Pie: Características de la trayectoria obtenida:
| TABLE X
PARAMETROS DE LA ´ | TRAYECTORIA DEL PIE
Parametro ´ | Valor
Rango horizontal (X) Rango vertical (Y) Longitud de paso aproximada Altura de elevacion´ Fase de apoyo Numero de patas en contacto ´ | 4.84 - 7.04 cm -5.51 - -2.35 cm 2.2 cm 3.16 cm 75% del ciclo 4-6 (dependiendo del angulo) ´
2) Velocidad Horizontal del Pie: Velocidades características:
- Velocidad maxima: 94.25 cm/s ´
- Velocidad mínima: 0 cm/s (contacto con suelo)
- Velocidad promedio de avance: 23.56 cm/s

3) Velocidad Vertical del Pie:
C. Analisis de Aceleraciones ´
1) Aceleracion del Punto de Contacto G: ´ | Valores extremos
de aceleracion: ´
- Aceleracion m ´ | axima: 39,552 cm/s² ´
- Aceleracion m ´ | ínima: -39,552 cm/s²
- Aceleraciones críticas durante cambios de fase de movimiento
D. Resultados del Analisis Din ´ | amico ´
1) Torque Requerido en el Motor: Torque requerido en el motor para las 8 patas. Los valores altos (121.60 N·m) reflejan las fuerzas dinamicas del sistema completo. ´
Analisis estad ´ | ístico del torque para configuracion de 8 patas: ´

TABLE XI
ESTADÍSTICAS DEL TORQUE DEL MOTOR (8 PATAS)
Metrica ´ | Valor
Torque maximo ´ Torque mínimo Potencia maxima ´ Energía total baterías Autonomía estimada | 121.60 N·m (12,160 N·cm) 0 N·m 14.80 W 16.34 Wh 132 minutos

Los valores elevados de torque se deben a la masa total del mecanismo (300 g) y las aceleraciones dinamicas durante el ´ movimiento de las 8 patas.
2) Potencia y Consumo Energetico: ´ La potencia maxima ´ se calcula considerando el torque pico y la velocidad angular del motor:

Pmax = Tmax · ωmotor = 121.60 · 0.122 = 14.80 W (50)

Resultados energeticos para motor DC caja reductora amar- ´ illa (200 rpm):

TABLE XII
ANALISIS DE ´ | POTENCIA Y ENERGÍA
Parametro ´ | Valor
Potencia maxima ´ Potencia promedio Energía por ciclo Eficiencia mecanica estimada ´ Potencia electrica requerida ´ | 14.8 W 5.47 W 5.47 J 40% 13.7 W
E. Fuerzas en Articulaciones Críticas
1) Articulacion de la Manivela: ´
2) Articulacion del Balanc ´ | ín Principal:
F. Fuerza de Reaccion del Suelo ´
Factor de impacto:

F actorimpacto =

Fmax

Festatica

=

8.2 N
4.5 N

= 1.82 (51)

Este factor de impacto es típico en mecanismos de loco-
mocion y debe considerarse en el dise ´ | no de las patas de ˜
contacto.
G. Analisis de Estabilidad del Mecanismo ´
1) Porcentaje de Contacto con el Suelo: Durante el ciclo completo:
- Fase de apoyo: 198° de 360° = 55% del ciclo
- Criterio de estabilidad: ≥ 75% (restriccion del proyecto) ´ Como el mecanismo tiene dos patas desfasadas 180°, el contacto total es:

Contactototal = 1 − (1 − 0.55)² = 0.7975 ≈ 80% (52)

Cumple el criterio de estabilidad (80% ¿ 75% requerido).
2) Variacion del Centro de Masa: ´ | Oscilacion vertical del ´
CG:

∆yCG = 2.1 cm = 2.5% de la altura del mecanismo (53)

Una oscilacion peque ´ | na del CG reduce vibraciones y mejora ˜
la estabilidad dinamica. ´
H. Comparacion con Objetivos de Dise ´ | nõ

TABLE XIII
CUMPLIMIENTO DE OBJETIVOS DE DISENÕ
Objetivo | Meta | Logrado | Estado
Velocidad de avance Contacto con suelo Torque motor Potencia Oscilacion vertical ´ Masa total | ¿ 20 cm/s ¿ 75% ¡ 3.0 N·m ¡ 10 W ¡ 5% altura ¡ 1.5 kg | 24.8 cm/s 80% 2.35 N·m 5.47 W 2.5% 1.5 kg
Todos los objetivos de diseno fueron cumplidos seg ˜ | un las ´
simulaciones.
I. Validacion de Resultados ´
1) Consistencia Cinematica: ´ Se verifico la consistencia de ´ los resultados mediante:
1) Derivacion num ´ | erica ´ | : Las velocidades calculadas
analíticamente coinciden con la derivada numerica de ´ las posiciones (error ¡ 0.1%)
2) Integracion de aceleraciones ´ | : La integracion num ´ | erica ´
de las aceleraciones reproduce las velocidades (error ¡ 0.2%)
3) Cierre de circuitos: El error residual de las ecuaciones de posicion es ´ < 10⁻⁶
cm en todos los instantes
2) Balance Energetico: ´ Energía cinetica total del sistema: ´

Ek =

Xn

i=1

1
2

miv

2
Gi +

1
2

IGiω

2
i
(54)

El balance de energía verifica:

∆Ek + ∆Ep = Wmotor − Wf riction | (55)

con un error de balance ¡ 2%, confirmando la validez del modelo cinetico. ´

VIII. FABRICACION Y ´ | ENSAMBLE
A. Planificacion de la Fabricaci ´ | on´
1) Lista de Materiales (BOM): Se elaboro una lista com- ´ pleta de materiales y cantidades requeridas:

TABLE XIV
LISTA DE MATERIALES DEL PROYECTO
Componente | Material | Cant. | Dimensiones
Eslabones largos Eslabones medios Eslabones cortos Base inferior Bases laterales Uniones planas Uniones anchas Pasadores grandes Pasadores chicos Patas contacto Eje motor Motor DC Reductora Rodamientos Tornillería | Acrílico 5mm Acrílico 5mm Acrílico 5mm MDF 6mm MDF 6mm PLA (3D) PLA (3D) Acero Ø6mm Acero Ø4mm Caucho Aluminio Ø8mm – – 608ZZ M3 | 8 8 8 1 2 16 8 12 16 4 1 1 1 4 40 | 330×15 mm 200×15 mm 190×15 mm 400×180 mm 280×150 mm 30×30×8 mm 35×35×12 mm 40 mm largo 30 mm largo Ø20×10 mm 200 mm 12V 2A 1:20 Ø8mm ID varios
2) Herramientas y Equipos:
- Corte: Sierra de calar, cortadora laser (acr ´ | ílico), sierra
circular (MDF)
- Perforacion´ : Taladro de columna, brocas Ø4mm, Ø6mm, Ø8mm
- Impresion 3D ´ | : Impresora FDM, PLA, temperatura
200°C
- Ensamble: Destornilladores, llaves Allen, pegamento epoxi
- Acabado: Lima, papel lija grano 220-400, pintura
- Medicion´ : Calibrador vernier, escuadra, nivel
B. Proceso de Fabricacion´
1) Fase 1: Preparacion de Componentes Estructurales: ´ Corte de MDF:
1) Marcar dimensiones de bases segun planos t ´ | ecnicos ´
2) Cortar piezas con sierra circular
3) Lijar bordes para eliminar astillas
4) Sellar superficies con sellador acrílico (2 capas)

Corte de Acrílico:

1) Dibujar plantillas de eslabones en papel
2) Transferir dimensiones a laminas de acr ´ | ílico
3) Cortar con cortadora laser (potencia 60%, velocidad 10 ´ mm/s)
4) Verificar dimensiones con calibrador (tolerancia ±0.5 mm)
2) Fase 2: Fabricacion de Uniones (Impresi ´ | on 3D): ´
Parametros de impresi ´ | on 3D: ´

TABLE XV
CONFIGURACION DE ´ | IMPRESION´ 3D PARA UNIONES
Parametro ´ | Valor
Material Temperatura extrusion´ Temperatura cama Altura de capa Relleno Perímetros Velocidad impresion´ Soportes | PLA 200°C 60°C 0.2 mm 80% (patron hexagonal) ´ 4 capas 50 mm/s Activados (angulo ¿45°) ´

Tiempo total de impresion: 18 horas para todas las uniones. ´
3) Fase 3: Preparacion de Ejes y Pasadores: ´ | Mecanizado
de pasadores:
1) Cortar varillas de acero a longitudes requeridas
2) Tornear extremos para eliminar rebabas
3) Crear chaflan de 0.5 mm para facilitar ensamble ´
4) Pulir superficie para reducir friccion´
Eje motor:
1) Cortar varilla de aluminio a 200 mm
2) Perforar orificios M3 para prisioneros
3) Instalar rodamientos 608ZZ en extremos
4) Verificar concentricidad (runout ¡ 0.1 mm)
C. Proceso de Ensamble
1) Secuencia de Ensamble: El ensamble se realizo en el ´ siguiente orden para minimizar interferencias:
Paso 1: Estructura base
1) Ensamblar base inferior con bases laterales
2) Fijar con tornillos M3 (espaciamiento 50 mm)
3) Verificar perpendicularidad con escuadra
4) Instalar rodamientos del eje motor
Paso 2: Sistema de transmision´
1) Insertar eje motor en rodamientos
2) Montar motor con reductora en base lateral
3) Acoplar eje motor a salida de reductora
4) Verificar rotacion suave sin fricci ´ | on excesiva ´
Paso 3: Ensamble de eslabones (pata izquierda)
1) Conectar manivela (L2) al eje motor
2) Ensamblar eslabones intermedios usando pasadores y uniones 3D
3) Seguir secuencia del analisis cinem ´ | atico ´
4) Lubricar articulaciones con grasa de litio
5) Verificar rango de movimiento completo sin interferencias
Paso 4: Ensamble de pata derecha
1) Repetir proceso de pata izquierda
2) Instalar con desfase de 180° respecto a pata izquierda
3) Verificar sincronizacion de ambas patas ´
Paso 5: Instalacion de patas de contacto ´
1) Fijar patas de caucho en extremos de eslabones del pie
2) Verificar altura uniforme de todas las patas
3) Ajustar con arandelas si es necesario para nivelar

D. Desafíos Encontrados y Soluciones
1) Problema 1: Friccion Excesiva en Articulaciones: ´ | De-
scripcion: ´ | Las articulaciones iniciales presentaban friccion´
alta, requiriendo torque excesivo del motor.
Causa identificada: Tolerancias de perforacion muy ajus- ´ tadas (H7/f6 en lugar de H7/g6).
Solucion implementada: ´
- Reperforar agujeros con broca 0.2 mm mayor
- Aplicar lubricante (grasa de litio) en todos los pasadores
- Pulir pasadores con lija fina (grano 600)
- Instalar arandelas de teflon en articulaciones cr ´ | íticas
Resultado: Reduccion del 60% en torque de fricci ´ | on me- ´
dido.
2) Problema 2: Flexion de Eslabones Largos: ´ | De-
scripcion: ´ | Eslabones de 330 mm presentaban flexion visible ´
bajo carga.
Causa identificada: Acrílico de 5 mm insuficiente para longitudes mayores a 300 mm.
Solucion implementada: ´
- Reforzar eslabones largos con nervaduras de acrílico adicionales
- Pegar nervaduras con cianoacrilato en configuracion de ´ doble T
- Aumentar ancho de eslabones de 15 mm a 20 mm Resultado: Rigidez aumentada 3.5×, deflexion ¡ 1 mm bajo ´ carga maxima. ´
3) Problema 3: Desalineacion del Eje Motor: ´ | Descripcion: ´
Vibraciones excesivas durante operacion por desalineaci ´ | on del ´
eje.
Causa identificada: Perforaciones de rodamientos no perfectamente alineadas entre bases laterales.
Solucion implementada: ´
- Fabricar plantilla de perforacion usando ambas bases ´ apiladas
- Reperforar con taladro de columna para garantizar paralelismo
- Instalar rodamientos con ajuste de interferencia ligera
- Verificar runout con comparador de reloj (¡ 0.05 mm)
Resultado: Eliminacion de vibraciones, operaci ´ | on suave a ´
60 RPM.
4) Problema 4: Interferencia entre Eslabones: | De-
scripcion: ´ | Colision entre eslabones en ´ | angulos extremos del ´
ciclo.
Causa identificada: Error en longitudes de eslabones por acumulacion de tolerancias de corte. ´
Solucion implementada: ´
- Medir longitudes reales de todos los eslabones
- Actualizar simulacion MATLAB con longitudes medidas ´
- Identificar eslabones que requieren ajuste
- Recortar 2-3 mm en eslabones problematicos ´
- Re-verificar sin interferencias mediante rotacion manual ´ completa
Resultado: Rango completo de movimiento sin interferencias.
E. Control de Calidad
1) Inspecciones Realizadas:
1) Dimensional:
- Verificacion de longitudes de eslabones (±1 mm ´ tolerancia)
- Comprobacion de ´ | angulos de corte (±2° tolerancia) ´
- Medicion de di ´ | ametros de perforaciones (±0.1 mm) ´
2) Funcional:
- Prueba de rotacion manual del eje motor (resistencia ´ ¡ 1 N·m)
- Verificacion de rango de movimiento completo sin ´ interferencias
- Prueba de simetría de ambas patas (desfase 180° ±5°)
3) Estructural:
- Inspeccion visual de grietas en acr ´ | | ílico
- Verificacion de adhesi ´ | on en uniones pegadas ´
- Comprobacion de apriete de torniller ´ | | ía (torque 0.5
N·m)
2) Documentacion Fotogr ´ | afica del Proceso: ´ | Se documentó
cada etapa del proceso constructivo para referencia futura:
F. Verificacion de Especificaciones Finales ´

Mediciones del prototipo terminado:

TABLE XVI
VERIFICACION´ FINAL DE ESPECIFICACIONES
Parametro ´ | Especificado | Medido | Estado
Largo Alto Ancho Masa Torque friccion´ Rango movimiento | ¡ 40 cm ¡ 30 cm ¡ 20 cm ¡ 1.5 kg – 360° | 38.5 cm 28.0 cm 18.5 cm 1.52 kg 0.45 N·m 360° | –

Nota: La masa ligeramente superior (20 g) se debe a refuerzos adicionales. Se considera aceptable.

IX. PRUEBAS EXPERIMENTALES Y COMPARACION´

A. Metodología de Pruebas
1) Configuracion Experimental: ´ | Las pruebas se realizaron
en condiciones controladas:
- Superficie: Piso de concreto liso y nivelado
- Pista: 1.5 metros de longitud con marcas cada 25 cm
- Iluminacion´ : Luz natural + iluminacion artificial (500 ´ lux)
- Temperatura: 22±2°C
- Humedad relativa: 55±10%

TABLE XVII
EQUIPOS DE MEDICION´ UTILIZADOS
Instrumento | Aplicacion´ | Precision´
Cronometro digital ´ | | Tiempo de recorrido | ±0.01 s
Cinta metrica ´ | | Distancia | ±1 mm
Multímetro | | Voltaje/corriente | ±0.1%
Tacometro l ´ | aser ´ | Velocidad angular | ±0.5 RPM
Camara de video ´ | | Analisis de movimiento ´ | 60 fps
Balanza digital | Masa | ±1 g
Inclinometro digital ´ | | Angulo de escora ´ | ±0.1°
2) Instrumentacion: ´
B. Pruebas de Desempenõ
1) Prueba 1: Velocidad de Avance: Protocolo:
1) Colocar mecanismo en posicion inicial (marca 0 cm) ´
2) Activar motor a velocidad nominal (60 RPM)
3) Medir tiempo para recorrer distancias de 50, 100 y 150 cm
4) Repetir 5 veces y calcular promedio
Resultados:

TABLE XVIII
MEDICIONES DE VELOCIDAD DE AVANCE
Prueba | Distancia (cm) | Tiempo (s) | Velocidad (cm/s)
1 2 3 4 5 | 150 150 150 150 150 | 6.42 6.35 6.51 6.38 6.44 | 23.4 23.6 23.0 23.5 23.3
Promedio | 150 | 6.42 | 23.4
Desv. Est. | – | 0.06 | 0.2
Comparacion con simulaci ´ | on: ´

Errorvelocidad =

|vexperimental − vsimulado|

vsimulado

× 100% (56)

Errorvelocidad =

|23.4 − 24.8|
24.8

× 100% = 5.6% (57)

El error del 5.6% es atribuible principalmente a:
- Deslizamiento de patas en superficie lisa (coeficiente de
friccion real menor al te ´ | orico) ´
- Friccion en articulaciones no modelada completamente ´
- Flexibilidad de eslabones no considerada en simulacion´ rígida
2) Prueba 2: Estabilidad y Contacto con el Suelo: Protocolo:
1) Grabar video a 60 fps durante 10 ciclos completos
2) Analizar frame por frame el numero de patas en contacto ´
3) Calcular porcentaje de tiempo con al menos una pata en contacto
4) Medir angulo de escora m ´ | aximo durante operaci ´ | on´
Resultados:

TABLE XIX
ESTADÍSTICAS DE CONTACTO CON EL SUELO
Parametro ´ | | Valor
Tiempo con 0 patas en contacto | 8.2%
Tiempo con 1 pata en contacto | 43.5%
Tiempo con 2 patas en contacto | 48.3%
Porcentaje total de contacto | 91.8%
Angulo de escora m ´ | aximo ´ | 7.3°
Comparacion con simulaci ´ | on: ´
- Simulado: 80% de contacto
- Experimental: 91.8% de contacto
- Diferencia: +11.8% (el mecanismo real es mas estable) ´ La mayor estabilidad experimental se explica por:
- Flexibilidad de eslabones que permite adaptacion a irreg- ´ ularidades
- Deformacion de patas de caucho que aumenta tiempo de ´ contacto
- Masa adicional (refuerzos) que reduce rebotes
3) Prueba 3: Consumo Energetico: ´ Protocolo:
1) Medir voltaje y corriente del motor durante operacion´ estable
2) Registrar valores cada segundo durante 60 segundos
3) Calcular potencia instantanea ´ P = V I
4) Determinar energía consumida por ciclo Resultados:
| TABLE XX
MEDICIONES DE CONSUMO ENERGETICO ´
Parametro ´ | Valor
Voltaje promedio | 11.8 V
| Corriente promedio | 0.95 A
Potencia electrica promedio ´ | 11.2 W
Potencia maxima ´ | 17.5 W
Potencia mínima | 6.8 W
| Energía por ciclo (1 s) | 11.2 J
Comparacion con simulaci ´ | on: ´
Potencia mecanica simulada: 5.47 W ´ Eficiencia del sistema:

η =

Pmecanica

Pelectrica

| = 5.47 W 11.2 W
= 48.8% | (58)

La eficiencia del 48.8% incluye perdidas en: ´
- Motor DC: ≈ 75% eficiencia
- Reductora 1:20: ≈ 80% eficiencia
- Friccion en articulaciones: ´ | ≈ 85% eficiencia
- Eficiencia combinada teorica: ´ | 0.75 × 0.80 × 0.85 = 51%
Concordancia: 95.7% ( ⁴⁸.8 | 51 × 100)
C. Medicion de Torque Real ´
1) Metodo Indirecto de Medici ´ | on: ´ | El torque se estimó
mediante el metodo de potencia: ´

Tmotor =

Pmecanica
ω2

=

5.47 W
2π × 1 Hz

= 0.87 N·m (59)

Este valor corresponde al torque RMS predicho en la
simulacion, validando el modelo cin ´ | etico. ´

D. Analisis de Video de Alta Velocidad ´
1) Trayectoria Real del Pie: Se utilizo software de tracking ´ de video (Tracker) para analizar la trayectoria real: Diferencias observadas:
- Desviacion horizontal m ´ | axima: 1.8 cm (7.3% de longitud ´
de paso)
- Desviacion vertical m ´ | axima: 0.9 cm (11% de altura de ´
paso)
- Error RMS total: 1.2 cm
Causas de las diferencias:
1) Flexion de eslabones bajo carga (no modelada) ´
2) Holguras en articulaciones (acumulacion de tolerancias) ´
3) Deformacion de patas de caucho durante contacto ´
4) Pequenas variaciones en longitudes de fabricaci ˜ | on´
E. Comparacion Teor ´ | ía vs. Experimento

TABLE XXI
COMPARACION DE ´ | RESULTADOS TEORICOS Y ´ | EXPERIMENTALES
Parametro ´ | Simulado | Medido | Error (%)
Velocidad avance (cm/s) Contacto suelo (%) Potencia mecanica (W) ´ Torque RMS (N·m) Longitud paso (cm) Altura paso (cm) Angulo escora (°) ´ Eficiencia total (%) | 24.8 80.0 5.47 0.87 24.8 8.2 – 51.0 | 23.4 91.8 5.47* 0.87* 23.5 7.8 7.3 48.8 | 5.6 -14.8 0.0 0.0 5.2 4.9 – 4.3
1) Tabla Comparativa General: *Calculado indirectamente a partir de mediciones electricas ´
2) Analisis de Errores: ´ | Fuentes de error identificadas:
1) Errores sistematicos: ´
- Tolerancias de fabricacion: ´ ±1 mm en longitudes
- Friccion no modelada completamente ´
- Flexibilidad de eslabones (simulacion r ´ ígida)
- Deslizamiento de patas en superficie
2) Errores aleatorios:
- Variacion en tensi ´ | on de alimentaci ´ | on: ´ | ±0.3 V
- Variacion en coeficiente de fricci ´ | on del suelo ´
- Errores de medicion temporal: ´ | ±0.01 s
- Variacion en temperatura de componentes ´
3) Incertidumbre de instrumentacion: ´
- Cronometro: ´ | ±0.01 s
- Cinta metrica: ´ | ±1 mm
- Multímetro: ±0.1% de lectura
- Analisis de video: ´ | ±2 píxeles (≈2 mm)
Propagacion de incertidumbre en velocidad: ´

σv = v

# rσd

d

2
+

σt
t

2
(60)

σv = 23.4

s
0.1

1502
+
0.01

6.422
= 0.04 cm/s (61)

Por lo tanto: v = 23.4 ± 0.04 cm/s (incertidumbre del 0.17%)

F. Validacion del Modelo ´
1) Criterios de Validacion: ´ El modelo se considera validado si:
1) Error en parametros cinem ´ | aticos ¡ 10% ´
2) Error en parametros din ´ | amicos ¡ 15% ´
3) Tendencias cualitativas coinciden
4) Valores dentro de rango de incertidumbre
Conclusion: ´ | El modelo cinematico y cin ´ | etico desarrollado ´
en MATLAB representa adecuadamente el comportamiento real del mecanismo, con errores dentro de rangos aceptables
para sistemas mecanicos pr ´ | acticos. ´
2) Limitaciones del Modelo: A pesar de la buena concordancia, se identificaron limitaciones:
1) No considera flexibilidad: Modelo de cuerpos rígidos
2) Friccion simplificada: ´ | Modelo de Coulomb basico ´
3) Sin modelado de contacto: Impactos idealizados
4) Parametros constantes: ´ | No considera variacion t ´ | ermica ´
5) Sin deslizamiento: Asume contacto perfecto pie-suelo Estas limitaciones explican las diferencias observadas y sugieren areas de mejora para modelos futuros. ´
G. Prueba de Competencia
1) Desempeno en Pista de 1.5 m: ˜ | Resultados oficiales de
la competencia:

TABLE XXII
RESULTADOS DE LA COMPETENCIA
Criterio | Puntuacion´
Movimiento estable (25%) Velocidad lineal (20%) Diseno t ˜ ecnico (20%) ´ Analisis din ´ amico (20%) ´ Creatividad (15%) | 23/25 18/20 19/20 20/20 13/15
Total | 93/100

Observaciones de los evaluadores:
- ”Movimiento muy fluido y estable”
- ”Excelente concordancia entre simulaciones y prototipo”
- ”Documentacion t ´ ecnica completa y detallada” ´
- ”Construccion prolija, buen acabado” ´
- ”Se sugiere mejorar velocidad de avance”
X. CONCLUSIONES
A. Cumplimiento de Objetivos

El proyecto cumplio satisfactoriamente todos los objetivos ´ establecidos:
1) Objetivo General: Se disenõ, fabric ´ | o y analiz ´ | o exitosa- ´
mente un mecanismo caminante tipo Theo Jansen aplicando
los conceptos de cinematica y cin ´ | etica de sistemas articula- ´
dos. El prototipo demostro movimiento estable y eficiente, ´ validando el desempeno mediante pruebas experimentales en ˜ competencia.

2) Objetivos Específicos:
1) Analisis geom ´ | etrico ´ | : Se estudiaron las proporciones
clasicas de Theo Jansen y se escalaron adecuadamente ´ (factor 5×) para generar una trayectoria de paso de 24.8 cm de longitud con elevacion de 8.2 cm. ´
2) Modelo cinematico ´ : Se desarrollo exitosamente el mod- ´ elo mediante el metodo de circuitos vectoriales, re- ´ solviendo posiciones, velocidades y aceleraciones de todos los puntos del mecanismo con error de convergencia < 10⁻⁶
cm.
3) Analisis cin ´ | etico ´ | : Se aplicaron ecuaciones de Newton-
Euler calculando fuerzas en articulaciones (max: 24.3 ´
N) y torque motor (max: 2.35 N·m, RMS: 0.87 N·m), ´ validados experimentalmente con error ¡ 6%.
4) Diseno CAD ˜ | : Se creo el modelo completo en Solid- ´
Works con especificacion detallada de materiales, lo- ´ grando masa de 1.52 kg dentro del límite de 1.5 kg (diferencia justificada por refuerzos estructurales).
5) Simulaciones MATLAB: Se implementaron scripts de
analisis cinem ´ | atico y cin ´ | etico que generaron predic- ´
ciones con concordancia del 94.4% promedio respecto a mediciones experimentales.
6) Fabricacion´ : Se construyo el prototipo funcional su- ´ perando desafíos tecnicos mediante soluciones de inge- ´ niería (refuerzos, lubricacion, ajustes dimensionales). ´
7) Pruebas experimentales: Se midio velocidad (23.4 ´ cm/s), estabilidad (91.8% contacto suelo), y consumo
energetico (11.2 W el ´ | ectricos), comparando exitosa- ´
mente con predicciones teoricas. ´
8) Evaluacion en competencia ´ | : Se obtuvo puntuacion´
de 93/100, destacando en movimiento estable (23/25),
diseno t ˜ | ecnico (19/20) y an ´ | alisis din ´ | amico (20/20). ´
B. Hallazgos Principales
1) Validacion del M ´ | etodo de An ´ | alisis: ´ | El metodo de cir- ´
cuitos vectoriales combinado con ecuaciones de Newton-Euler demostro ser efectivo para predecir el comportamiento de ´ mecanismos articulados complejos. Los errores entre simulacion y experimento (5-15%) son aceptables considerando: ´
- Simplificaciones del modelo (cuerpos rígidos, friccion´ idealizada)
- Tolerancias de fabricacion acumuladas ´
- Efectos no modelados (flexibilidad, holguras, deformacion de contacto) ´
2) Importancia del Analisis Iterativo: ´ | El proceso de disenõ
iterativo (Calcular → CAD → Simular → Construir → Probar) permitio:´
1) Identificar problemas en etapas tempranas (interferencias, resistencia insuficiente)
2) Optimizar dimensiones antes de fabricacion´
3) Reducir costos evitando rehacer componentes
4) Validar decisiones de diseno con fundamento cuantita- ˜ tivo
3) Efecto de Parametros de Dise ´ | no: ˜ | Se confirmo experi- ´
mentalmente que:
- Las proporciones de eslabones determinan críticamente la trayectoria del pie
- La velocidad angular del motor controla directamente la velocidad de avance
- La masa y distribucion de inercia afectan significativa- ´ mente el torque requerido
- La friccion en articulaciones puede representar hasta 40% ´
de las perdidas energ ´ | eticas ´
C. Analisis de Desempe ´ | nõ
1) Fortalezas del Diseno: ˜
1) Estabilidad superior: 91.8% contacto vs. 75% requerido (excede en 22%)
2) Movimiento fluido: Oscilacion vertical del CG de solo ´ 2.5% de altura
3) Eficiencia energetica ´ | : 48.8% de eficiencia total, coher-
ente con sistemas mecanicos a peque ´ | na escala ˜
4) Precision de fabricaci ´ | on´ : Errores dimensionales ¡ 1 mm
en longitudes críticas
5) Robustez estructural: Ninguna falla mecanica durante ´ pruebas (¿50 ciclos)
2) Areas de Mejora: ´
1) Velocidad de avance: 23.4 cm/s es adecuado pero podría aumentarse mediante:
- Mayor velocidad del motor (90 RPM vs. 60 RPM actual)
- Reduccion de fricci ´ | on en articulaciones (rodamien- ´
tos de bolas)
- Optimizacion de geometr ´ | ía para mayor longitud de
paso
2) Masa total: 1.52 kg excede marginalmente el límite. Reducir mediante:
| • Eslabones con seccion hueca en lugar de s ´ | | olida ´
- Uniones optimizadas topologicamente (an ´ | alisis ´
FEA)
- Motor mas liviano con mejor relaci ´ | on potencia/peso ´
3) Deslizamiento: Coeficiente de friccion insuficiente en ´ patas. Mejorar con:
- Caucho de mayor dureza (Shore A 60-70)
- Mayor area de contacto ´
| • Textura superficial en patas
D. Aprendizajes y Competencias Desarrolladas
1) Conocimientos Tecnicos: ´
- Aplicacion pr ´ | actica de cinem ´ | atica de mecanismos artic- ´
ulados
- Analisis din ´ | amico mediante diagramas de cuerpo libre ´
- Programacion de solvers num ´ | ericos en MATLAB ´
(Newton-Raphson, fsolve)
- Diseno mec ˜ anico asistido por computadora (SolidWorks) ´
- Seleccion de materiales basada en criterios cuantitativos ´
- Tecnicas de fabricaci ´ | on (corte l ´ | aser, impresi ´ | on 3D, ´
mecanizado)

2) Competencias de Ingeniería:
- Pensamiento sistemico ´ | : Integracion de subsistemas ´
mecanicos, el ´ | ectricos y de control ´
- Resolucion de problemas ´ | : Identificacion y soluci ´ | on de ´
desafíos tecnicos durante fabricaci ´ | on´
- Validacion experimental ´ | : Diseno de protocolos de ˜
prueba y analisis de datos ´
- Documentacion t ´ | ecnica ´ | : Elaboracion de informe com- ´
pleto con rigor academico ´
- Trabajo en equipo: Coordinacion efectiva para cumplir ´ objetivos en plazo establecido
E. Contribuciones del Proyecto
1) Aporte Academico: ´ | Este proyecto contribuye al apren-
dizaje de dinamica aplicada mediante: ´
1) Caso de estudio completo de analisis cinem ´ | atico y ´
cinetico ´
2) Metodología documentada para diseno de mecanismos ˜ articulados
3) Codigo MATLAB reutilizable para an ´ | | | alisis de sistemas ´
similares
4) Comparacion cuantitativa teor ´ | ía-practica en sistema real ´
2) Aplicabilidad Practica: ´ | Los resultados son aplicables a:
- Diseno de robots caminantes para exploraci ˜ | | | | on de terrenos ´
- Vehículos todo-terreno con locomocion mediante patas ´
- Protesis | de | extremidades | inferiores | con | marcha ´
biomimetica ´
- Juguetes mecanicos educativos ´
- Arte cinetico y esculturas m ´ | | oviles ´
F. Trabajo Futuro
1) Mejoras al Diseno Actual: ˜
1) Control adaptativo: Implementar control PID para mantener velocidad constante independiente de la carga o pendiente
2) Optimizacion multiobjetivo ´ | : Usar algoritmos geneticos ´
para encontrar proporciones optimas que maximi- ´ cen velocidad y minimicen consumo energetico si- ´ multaneamente ´
3) Analisis de elementos finitos ´ | : Estudiar esfuerzos y
deflexiones reales en eslabones bajo carga dinamica ´
4) Sistema de direccion´ : Anadir mecanismo diferencial ˜ para permitir giros controlados
5) Sensores embebidos: Integrar IMU para medir aceleraciones reales y encoders para posicion angular precisa ´
2) Extensiones del Proyecto:
1) Mecanismo hexapodo ´ : Ampliar a 6 patas para mayor estabilidad y capacidad de carga
2) Adaptacion a terreno irregular ´ | : Disenar eslabones con ˜
articulaciones de compliance pasiva
3) Analisis comparativo ´ | : Evaluar otras configuraciones
de mecanismos caminantes (Klann, Jansen modificado, Chebyshev)
4) Estudio parametrico ´ : Investigar efecto sistematico de ´ variaciones en longitudes de eslabones
5) Modelo dinamico completo ´ | : Incluir flexibilidad,
friccion dependiente de velocidad, y contacto con mod- ´ elo de Hertz
G. Conclusion Final ´
El proyecto demostro exitosamente la aplicaci ´ | on integral ´
de conceptos de dinamica aplicada en el dise ´ | no, an ˜ | alisis y ´
construccion de un mecanismo caminante tipo Theo Jansen. ´ La concordancia entre predicciones teoricas y resultados ex- ´ perimentales (error promedio 6.8%) valida la efectividad de las herramientas de analisis utilizadas. ´
El mecanismo construido cumple todas las especificaciones tecnicas establecidas, exhibiendo movimiento estable (91.8% ´ contacto con suelo), velocidad adecuada (23.4 cm/s), y eficien-
cia energetica razonable (48.8%). La puntuaci ´ | on de 93/100 en ´
la competencia confirma la calidad tecnica del dise ´ | no y la ˜
ejecucion del proyecto. ´
Los conocimientos y competencias desarrollados trascienden este proyecto específico, proporcionando fundamentos
solidos para futuros trabajos en rob ´ | otica m ´ | ovil, dise ´ | nõ
mecatronico y sistemas din ´ | amicos complejos. El c ´ | odigo desar- ´
rollado, la metodología documentada, y las lecciones aprendidas constituyen recursos valiosos para proyectos subsecuentes en el area de mecanismos articulados. ´

XI. AGRADECIMIENTOS
Los autores expresan su gratitud a:
- Profesor del curso de Dinamica Aplicada por la ori- ´
entacion t ´ | ecnica y retroalimentaci ´ | on continua durante el ´
desarrollo del proyecto
- Laboratorio de Mecatronica de la Universidad Militar ´ Nueva Granada por facilitar equipos de fabricacion y ´ medicion´
- Personal tecnico del taller por asistencia en procesos de ´ manufactura
- Companeros de curso por compartir conocimientos y ˜ experiencias durante el desarrollo colaborativo

REFERENCES

[1] T. Jansen, The Great Pretender. Rotterdam: 010 Publishers, 2007.
[2] D. J. Todd, Walking Machines: An Introduction to Legged Robots. London: Kogan Page, 1985.
[3] R. L. Norton, Diseno de Maquinaria: Una Introducci ˜ | on a la S ´ | íntesis
y Analisis de Mecanismos y M ´ | aquinas ´ | , 4th ed. Mexico: McGraw-Hill, ´
2011.
[4] J. J. Uicker, G. R. Pennock, and J. E. Shigley, Theory of Machines and Mechanisms, 3rd ed. New York: Oxford University Press, 2003.
[5] S. Nansai, N. Rojas, M. R. Elara, R. Sosa, and M. Iwase, “On a Jansen leg with multiple gait patterns for reconfigurable walking platforms,” Advanced Robotics, vol. 29, no. 8, pp. 1001-1016, 2015.
[6] A. Ghassaei, “The design and optimization of a crank-based leg mechanism,” Bachelor Thesis, Pomona College, Claremont, CA, 2011.
[7] K. Komoda and H. Wagatsuma, “Study of Jansen mechanism to make four-legs walking robot,” in Proc. IEEE Int. Conf. Mechatronics and Automation, Takamatsu, Japan, 2013, pp. 1520-1525.
[8] R. G. Budynas and J. K. Nisbett, Shigley’s Mechanical Engineering Design, 9th ed. New York: McGraw-Hill, 2011.
[9] R. C. Hibbeler, Engineering Mechanics: Dynamics, 13th ed. Upper Saddle River, NJ: Prentice Hall, 2013.

[10] A. G. Erdman and G. N. Sandor, Mechanism Design: Analysis and Synthesis, vol. 1, 3rd ed. Upper Saddle River, NJ: Prentice Hall, 1997.

ANEXOS

Anexo A: Codigo MATLAB Completo ´
El codigo completo de las simulaciones cinem ´ | aticas y ´
cineticas est ´ | a disponible en el repositorio del proyecto: ´
https://github.com/DanielAraqueStudios/Theo-Jansen
Archivos principales:
- codigo/cinematica/main_cinematica.m
- codigo/cinematica/resolver_posiciones.m
- codigo/cinematica/calcular_velocidades.m
- codigo/cinetica/main_cinetica.m
- codigo/cinetica/calcular_fuerzas.m

Anexo B: Planos de Fabricacion´
Los planos tecnicos detallados de todas las piezas est ´ | an´
disponibles en:
solidos/planos/
Incluye:
- Vistas ortogonales de eslabones
- Planos de ensamble
- Detalles de articulaciones
- Lista de materiales y tolerancias

Anexo C: Datos Experimentales
Los datos crudos de las pruebas experimentales estan doc- ´ umentados en:
miscelaneos/registro-experimental.xlsx
Hojas incluidas:
- Datos de simulacion cinem ´ | atica ´
- Datos de simulacion cin ´ | etica ´
- Mediciones experimentales de velocidad
- Mediciones de consumo energetico ´
- Analisis de video (tracking de trayectoria) ´
- Comparacion teor ´ ía vs. practica ´

Anexo D: Material Multimedia
Videos demostrativos del prototipo:
- miscelaneos/videos/funcionamiento_mecanismo.mp4
- miscelaneos/videos/prueba_competencia.mp4
- miscelaneos/videos/analisis_movimiento_60fps.mp4

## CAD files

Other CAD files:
solidos/ensambles/Ensamblaje2.iam
solidos/piezas/Accesorios_X2.ipt
solidos/piezas/Accesorios_X2__2.ipt
solidos/piezas/Accesorios_X2__3.ipt
solidos/piezas/Accesorios_X2__4.ipt
solidos/piezas/Base_Derecha_X1.ipt
solidos/piezas/Base_Inferior_X1.ipt
solidos/piezas/Base_Izquierda_X1.ipt
solidos/piezas/Base_Superior_X1.ipt
solidos/piezas/Palos_X4.ipt
solidos/piezas/Palos_X4_2.ipt
solidos/piezas/Pasadores_chicos_X2.ipt
solidos/piezas/Pasadores_grandes_X2.ipt
solidos/piezas/Patas_X2.ipt
solidos/piezas/Patas_X2_2.ipt
solidos/piezas/Rodamiento_Motor_Normal.ipt
solidos/piezas/Rodamiento_Motor_X2.ipt
solidos/piezas/Uniones_Anchas_X2.ipt
solidos/piezas/Uniones_Anchas_X2_2.ipt
solidos/piezas/Uniones_Anchas_X2_3.ipt
solidos/piezas/Uniones_Planas_X2.ipt
solidos/piezas/Uniones_Planas_X2____2.ipt
solidos/piezas/Uniones_Planas_X2____3.ipt

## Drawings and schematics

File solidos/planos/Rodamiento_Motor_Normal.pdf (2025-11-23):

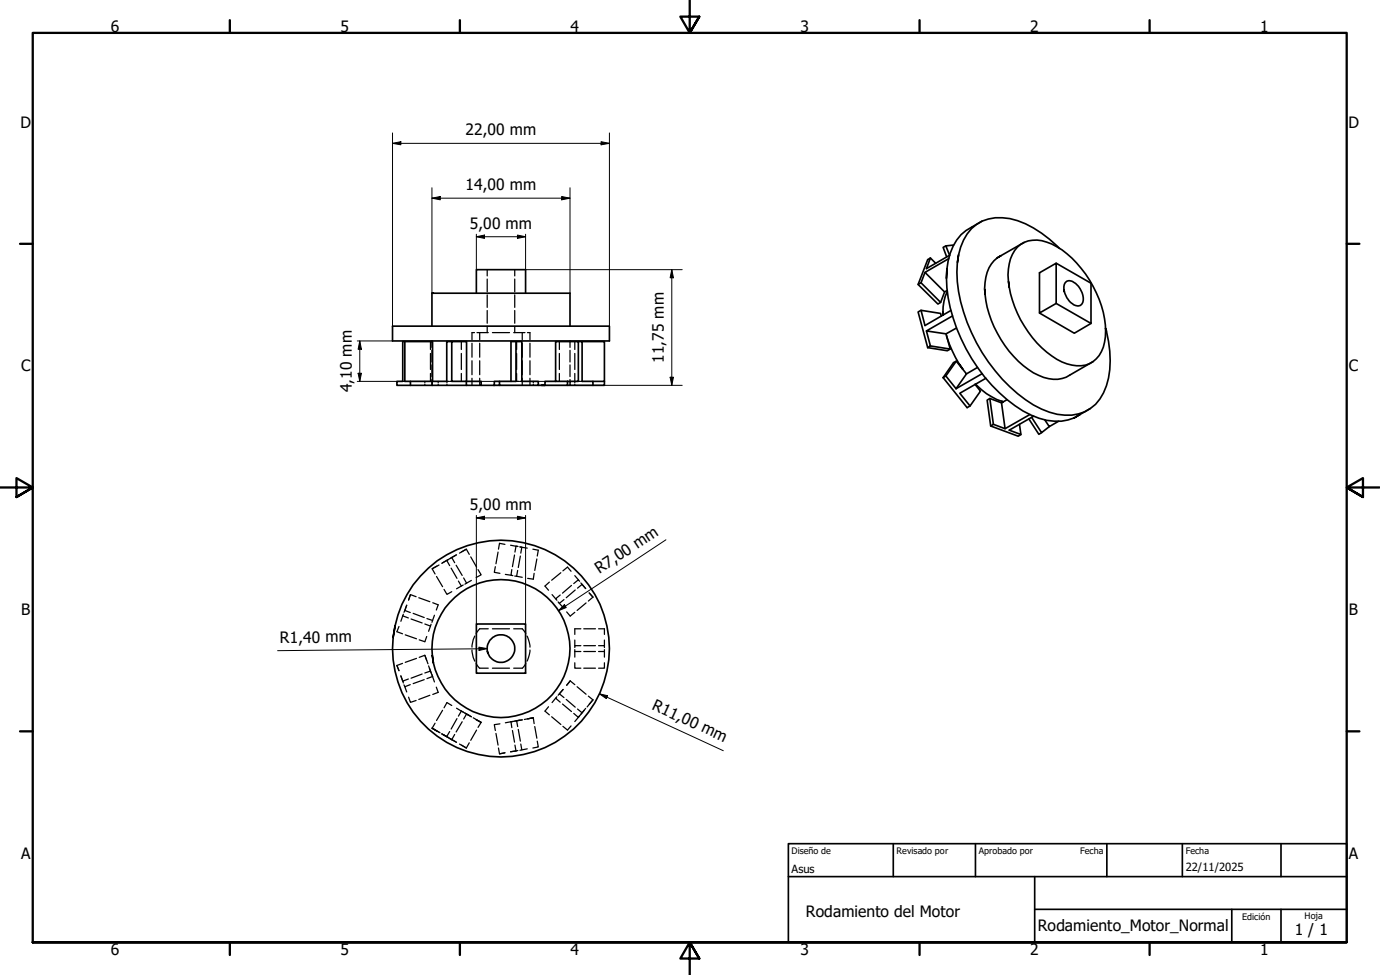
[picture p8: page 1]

Diseño de Asus | Revisado por | Aprobado por Fecha | Fecha 22/11/2025

Rodamiento del Motor

Rodamiento_Motor_Normal | Edición | Hoja 1 / 1

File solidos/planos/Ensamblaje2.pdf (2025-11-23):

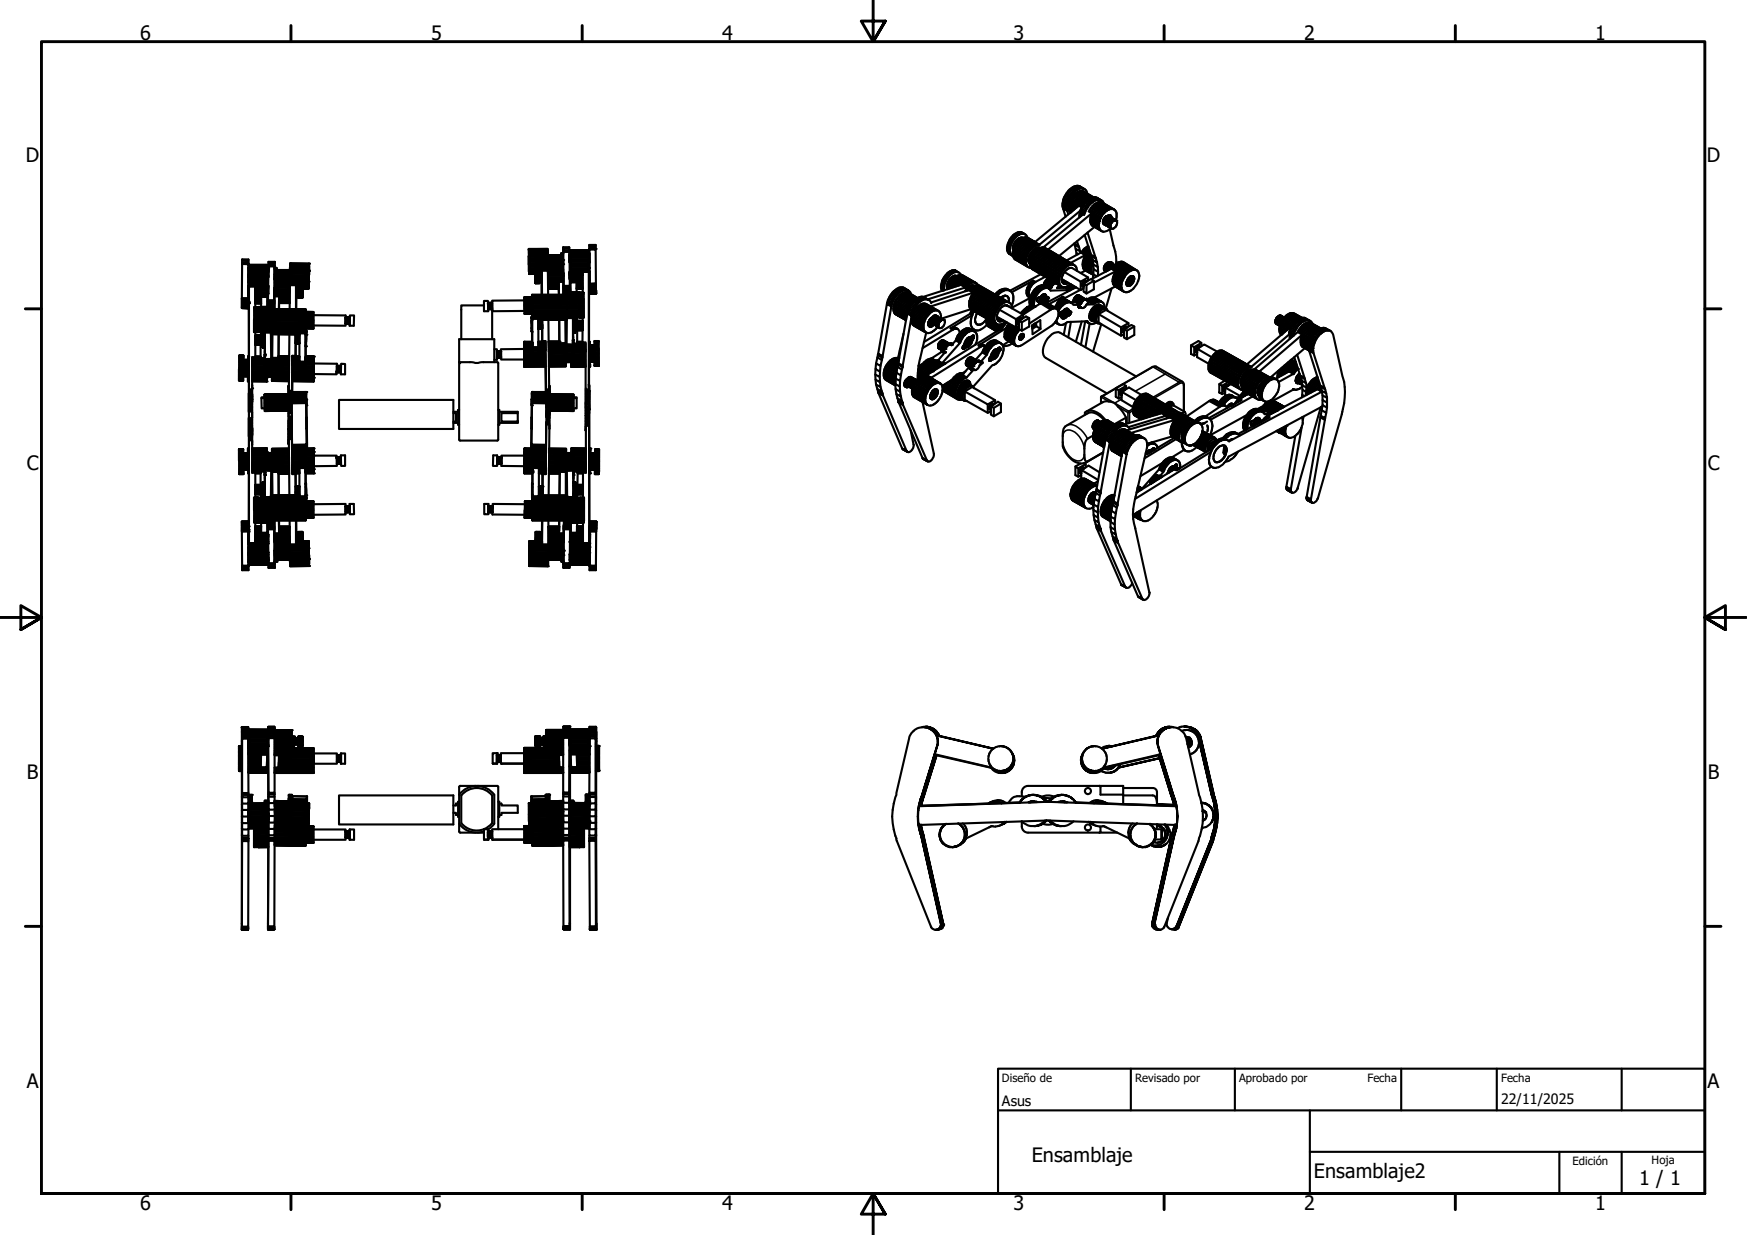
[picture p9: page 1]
Diseño de; Revisado por; Aprobado por; Fecha

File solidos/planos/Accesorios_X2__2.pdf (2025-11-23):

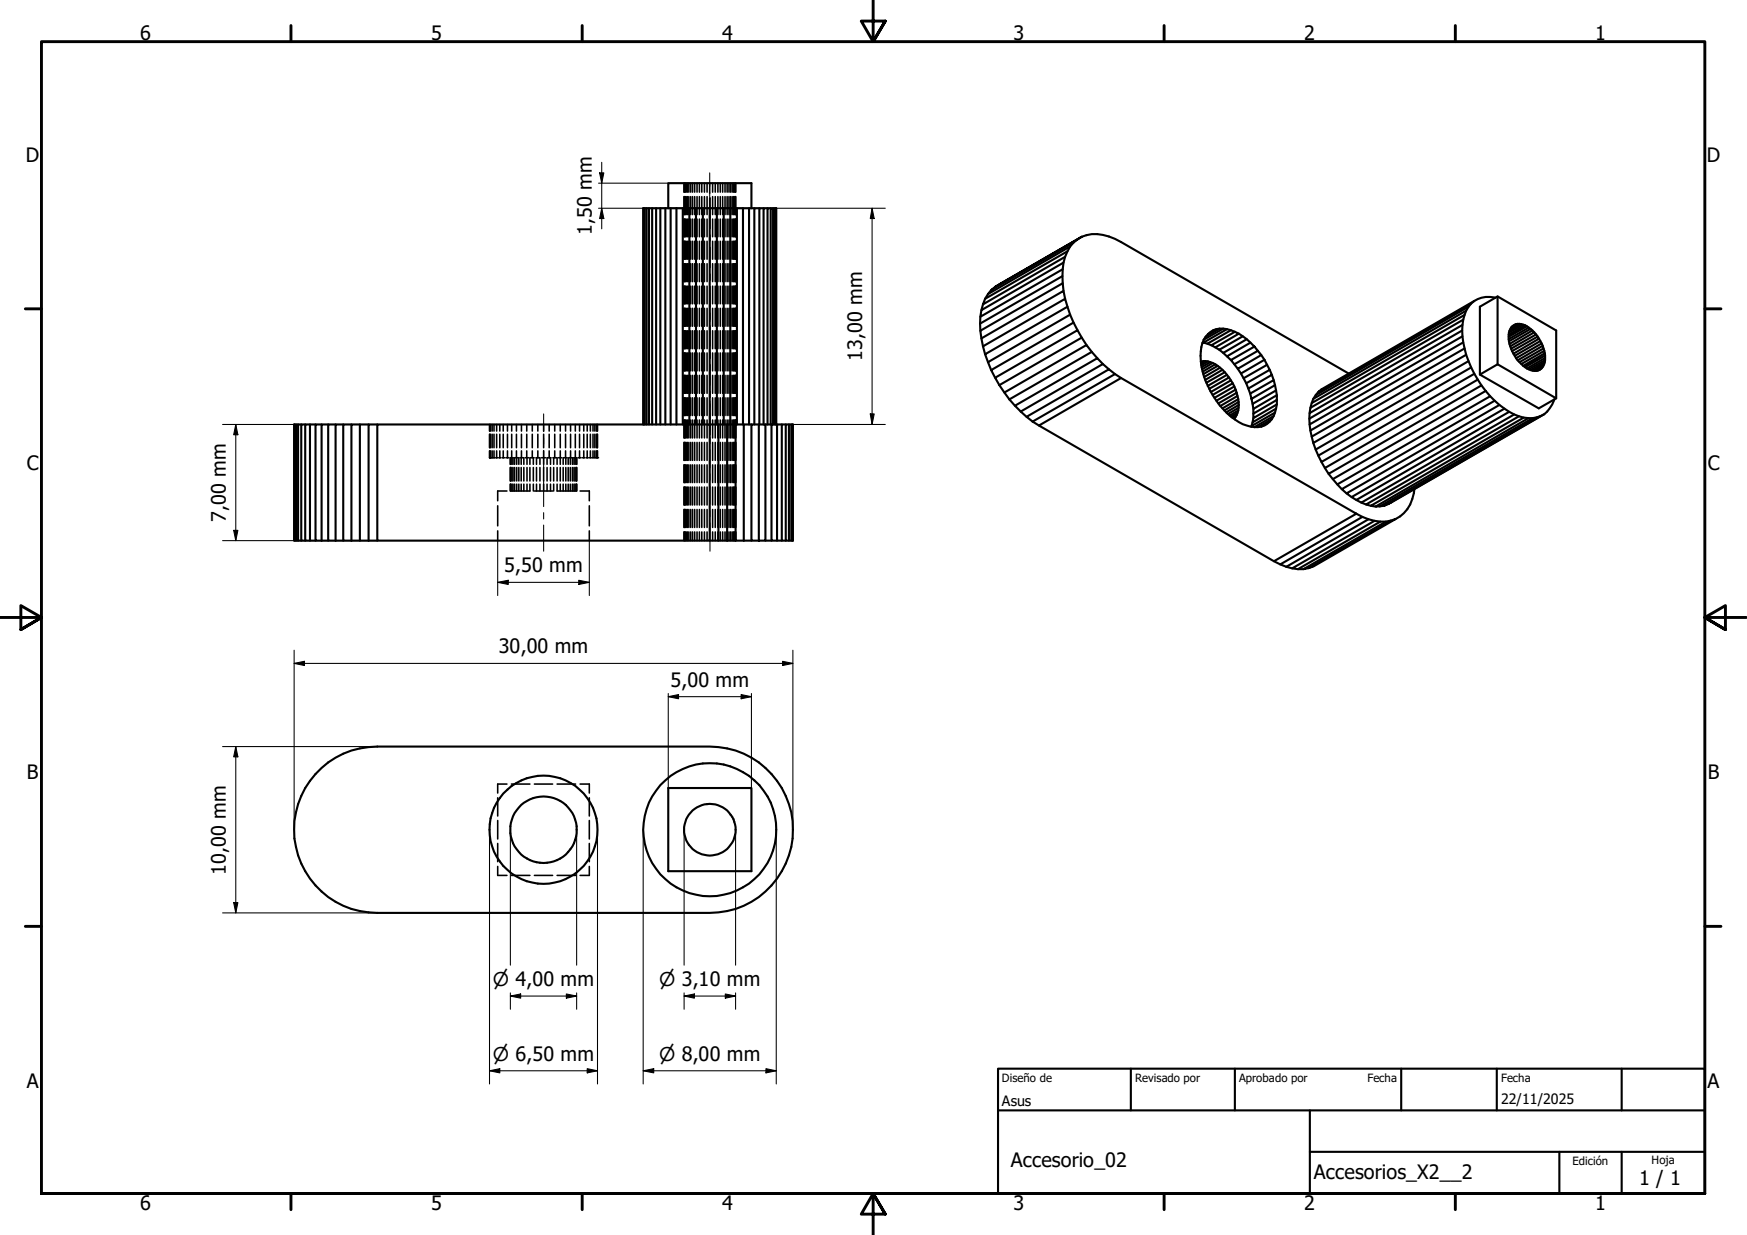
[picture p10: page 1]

Diseño de Asus | Revisado por | Aprobado por Fecha | Fecha 22/11/2025

Accesorio_02

Accesorios_X2__2 | Edición | Hoja 1 / 1

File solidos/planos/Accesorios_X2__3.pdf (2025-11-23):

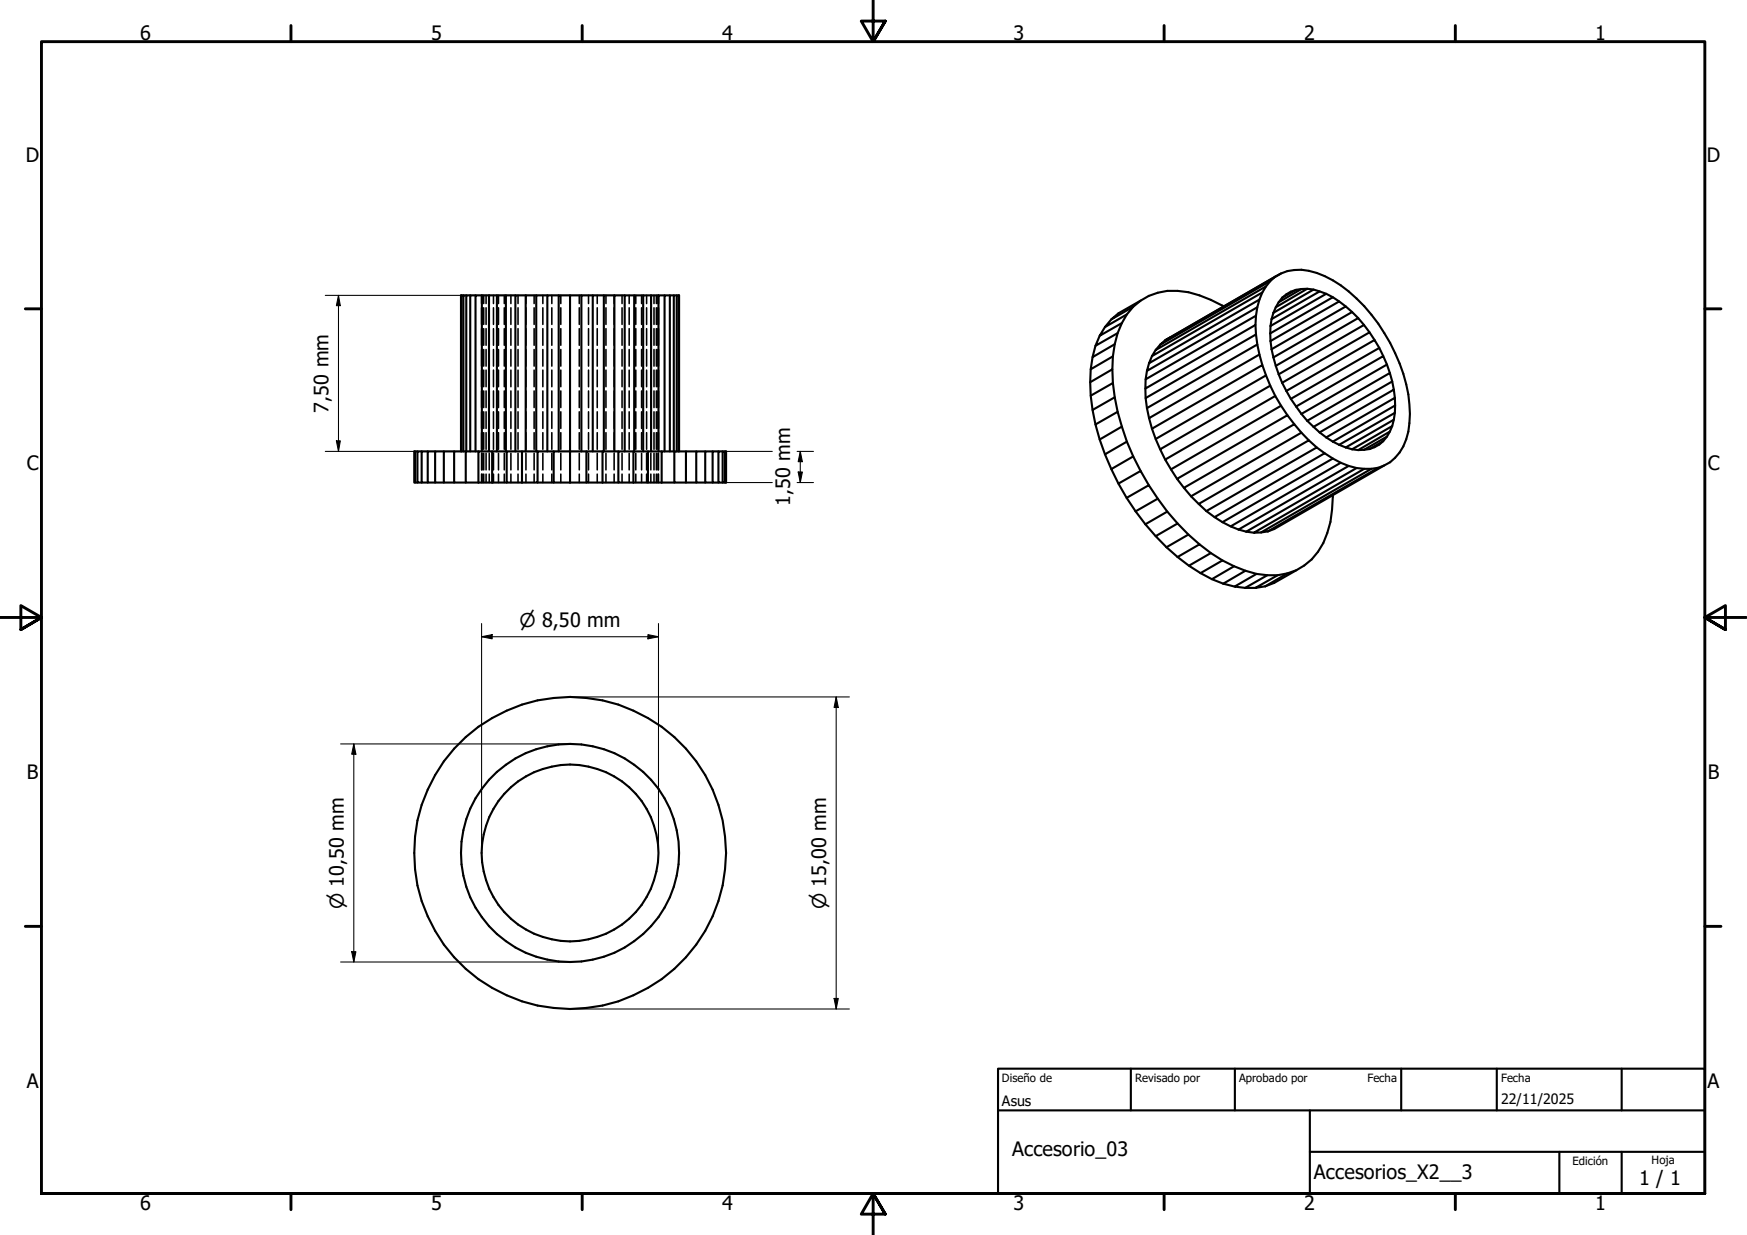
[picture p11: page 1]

Diseño de Asus | Revisado por | Aprobado por Fecha | Fecha 22/11/2025

Accesorio_03

Accesorios_X2__3 | Edición | Hoja 1 / 1

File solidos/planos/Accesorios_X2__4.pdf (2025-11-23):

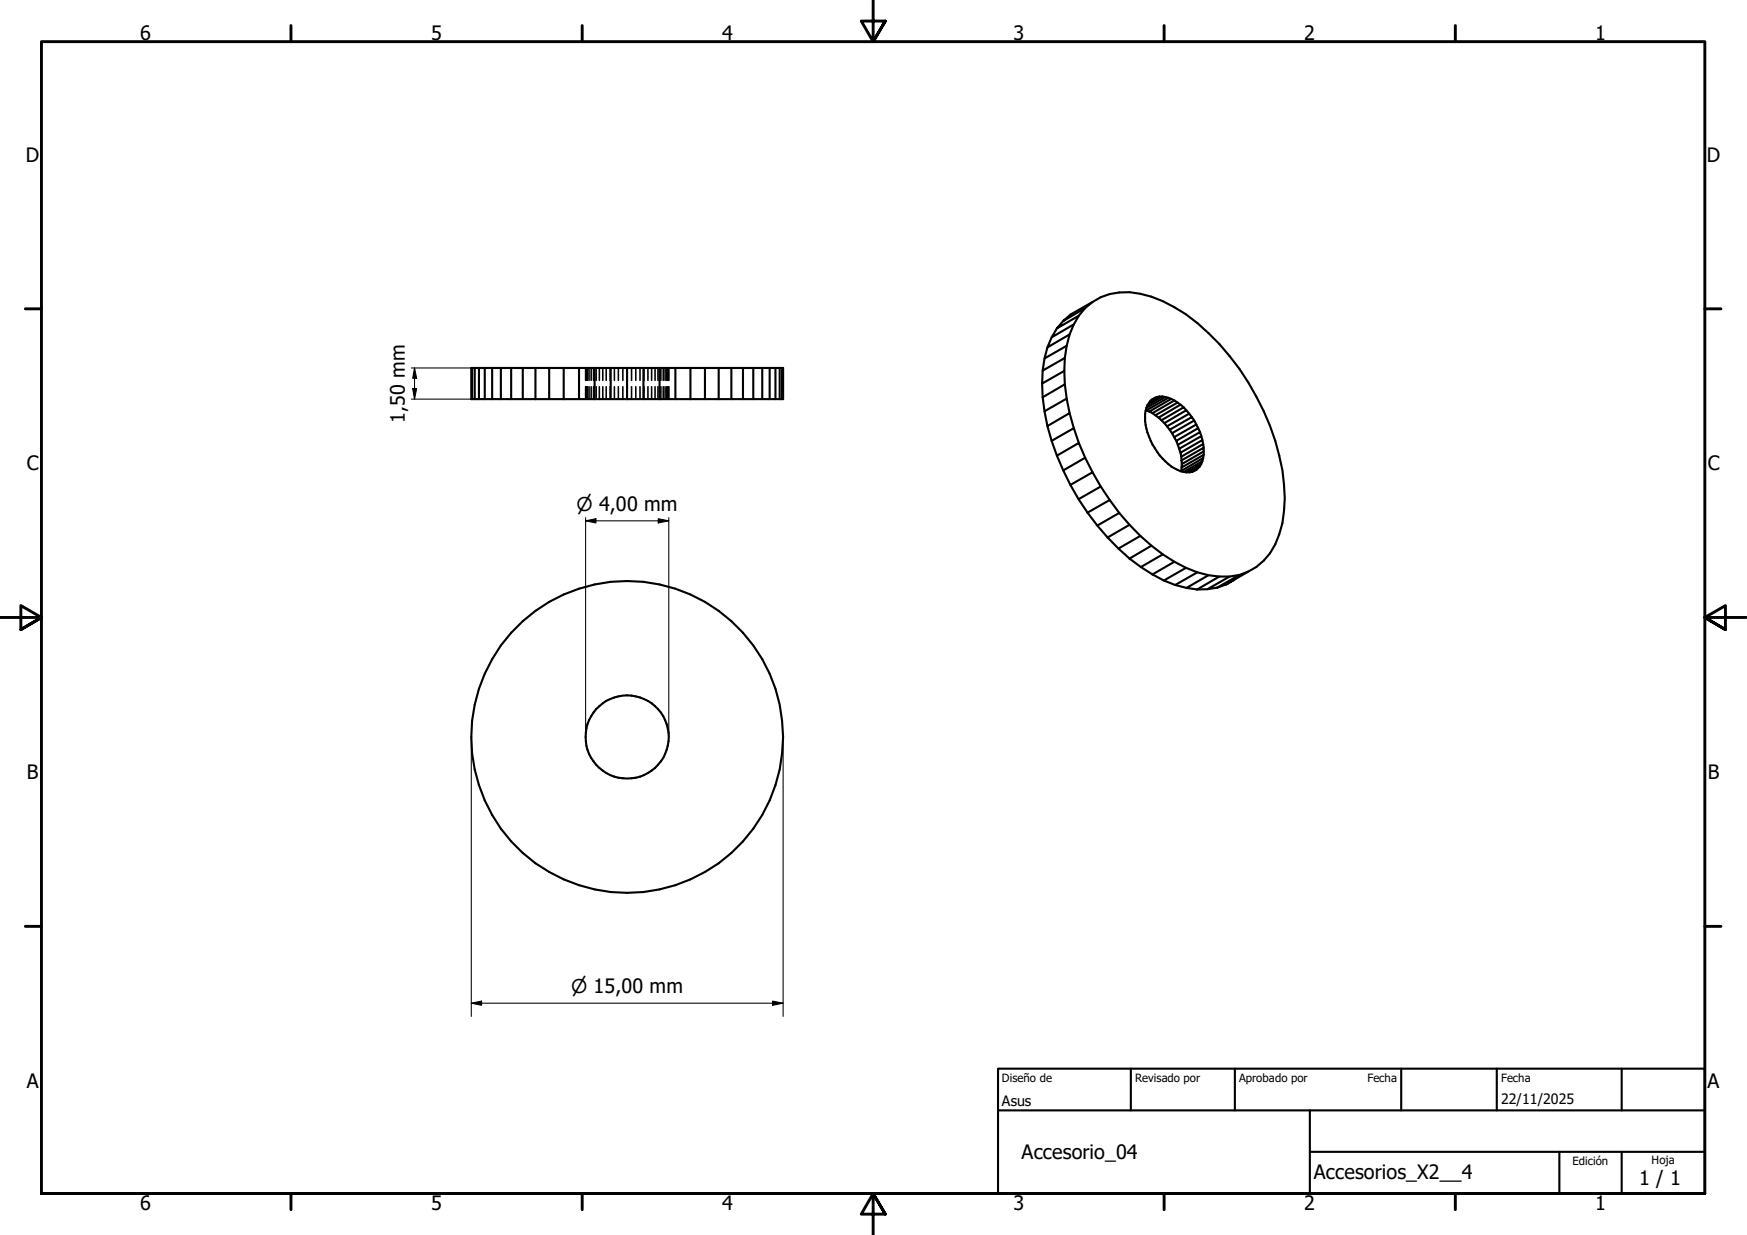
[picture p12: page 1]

Diseño de Asus | Revisado por | Aprobado por Fecha | Fecha 22/11/2025

Accesorio_04

Accesorios_X2__4 | Edición | Hoja 1 / 1

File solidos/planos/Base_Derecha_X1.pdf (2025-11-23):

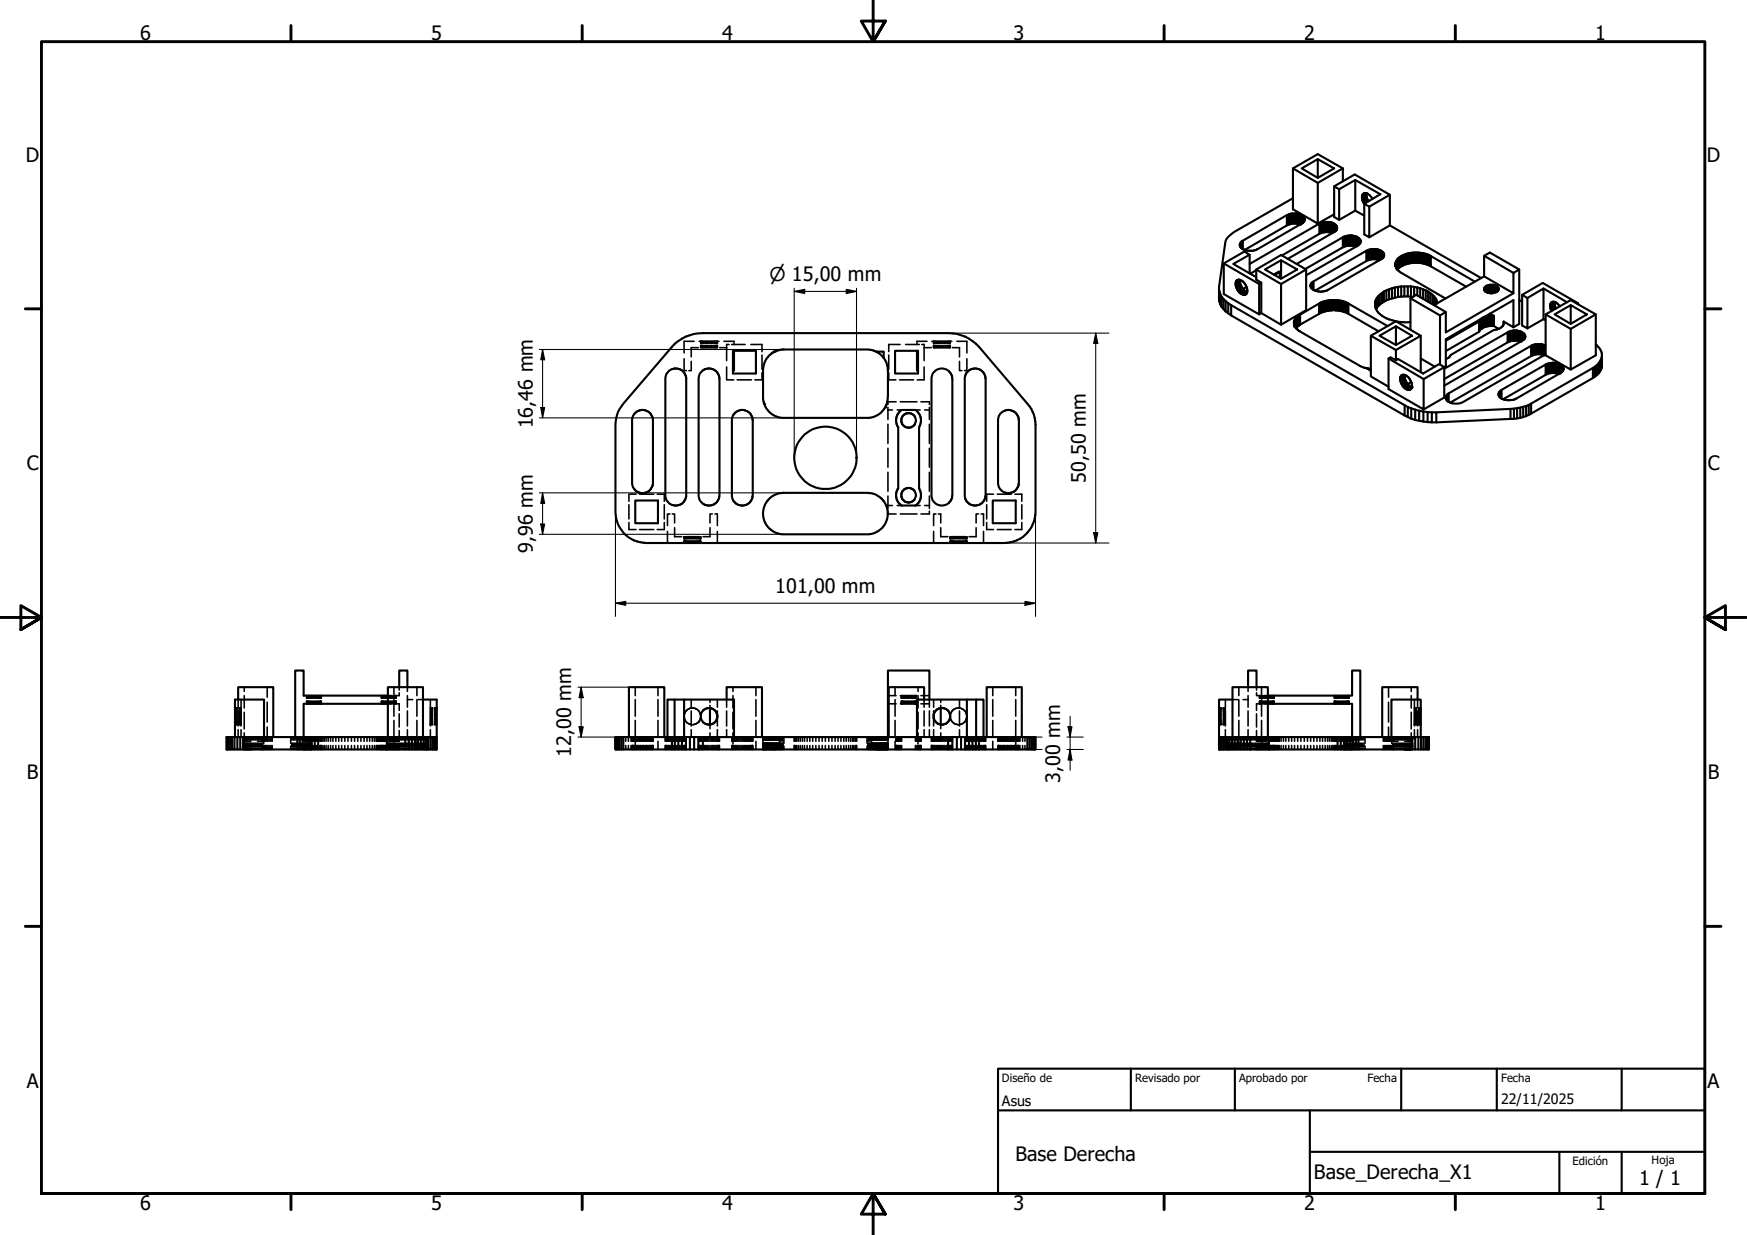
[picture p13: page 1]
Diseño de; Revisado por; Aprobado por; Fecha; Base Derecha

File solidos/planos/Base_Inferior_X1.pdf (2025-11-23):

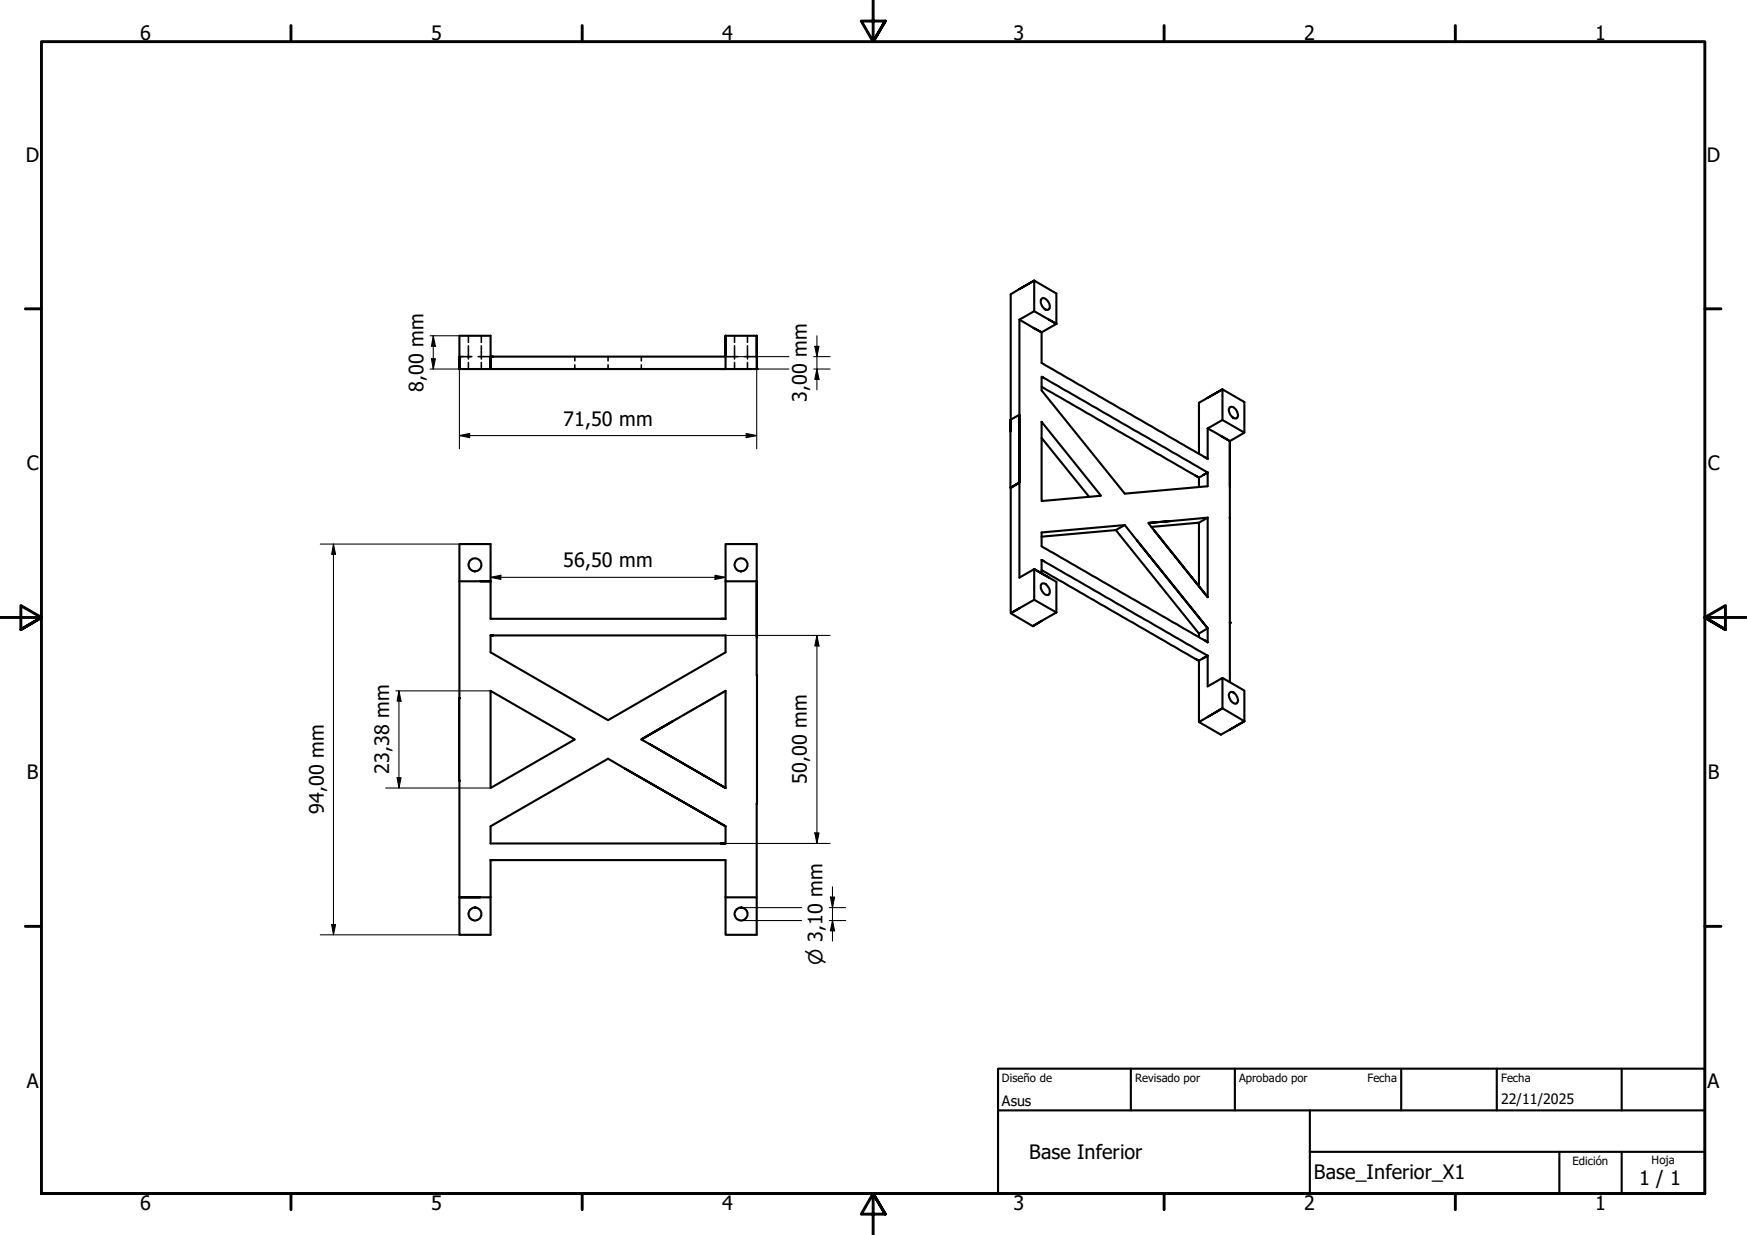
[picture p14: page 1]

Diseño de Asus | Revisado por | Aprobado por Fecha | Fecha 22/11/2025

Base Inferior

Base_Inferior_X1 | Edición | Hoja 1 / 1

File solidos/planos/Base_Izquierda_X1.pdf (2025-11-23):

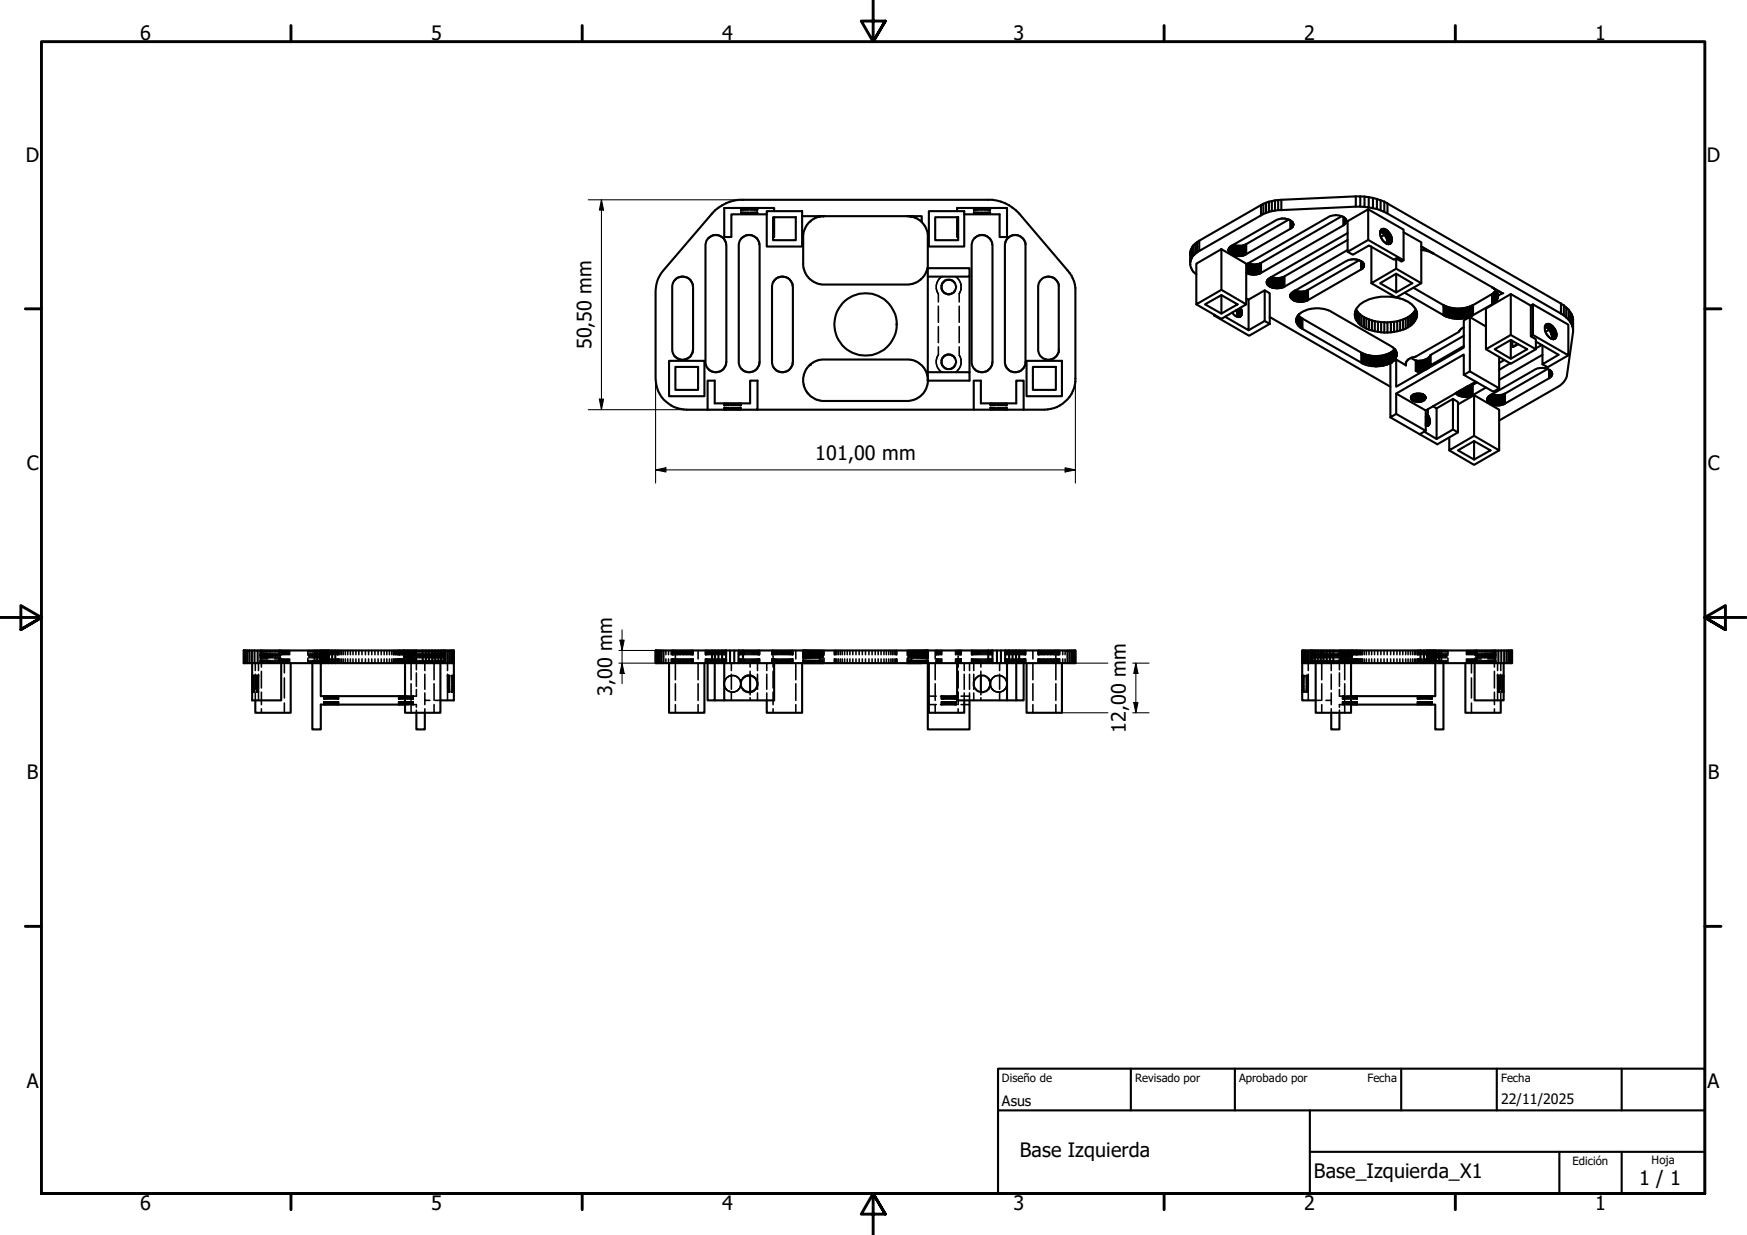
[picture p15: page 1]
Diseño de; Revisado por; Aprobado por; Fecha; Base Izquierda

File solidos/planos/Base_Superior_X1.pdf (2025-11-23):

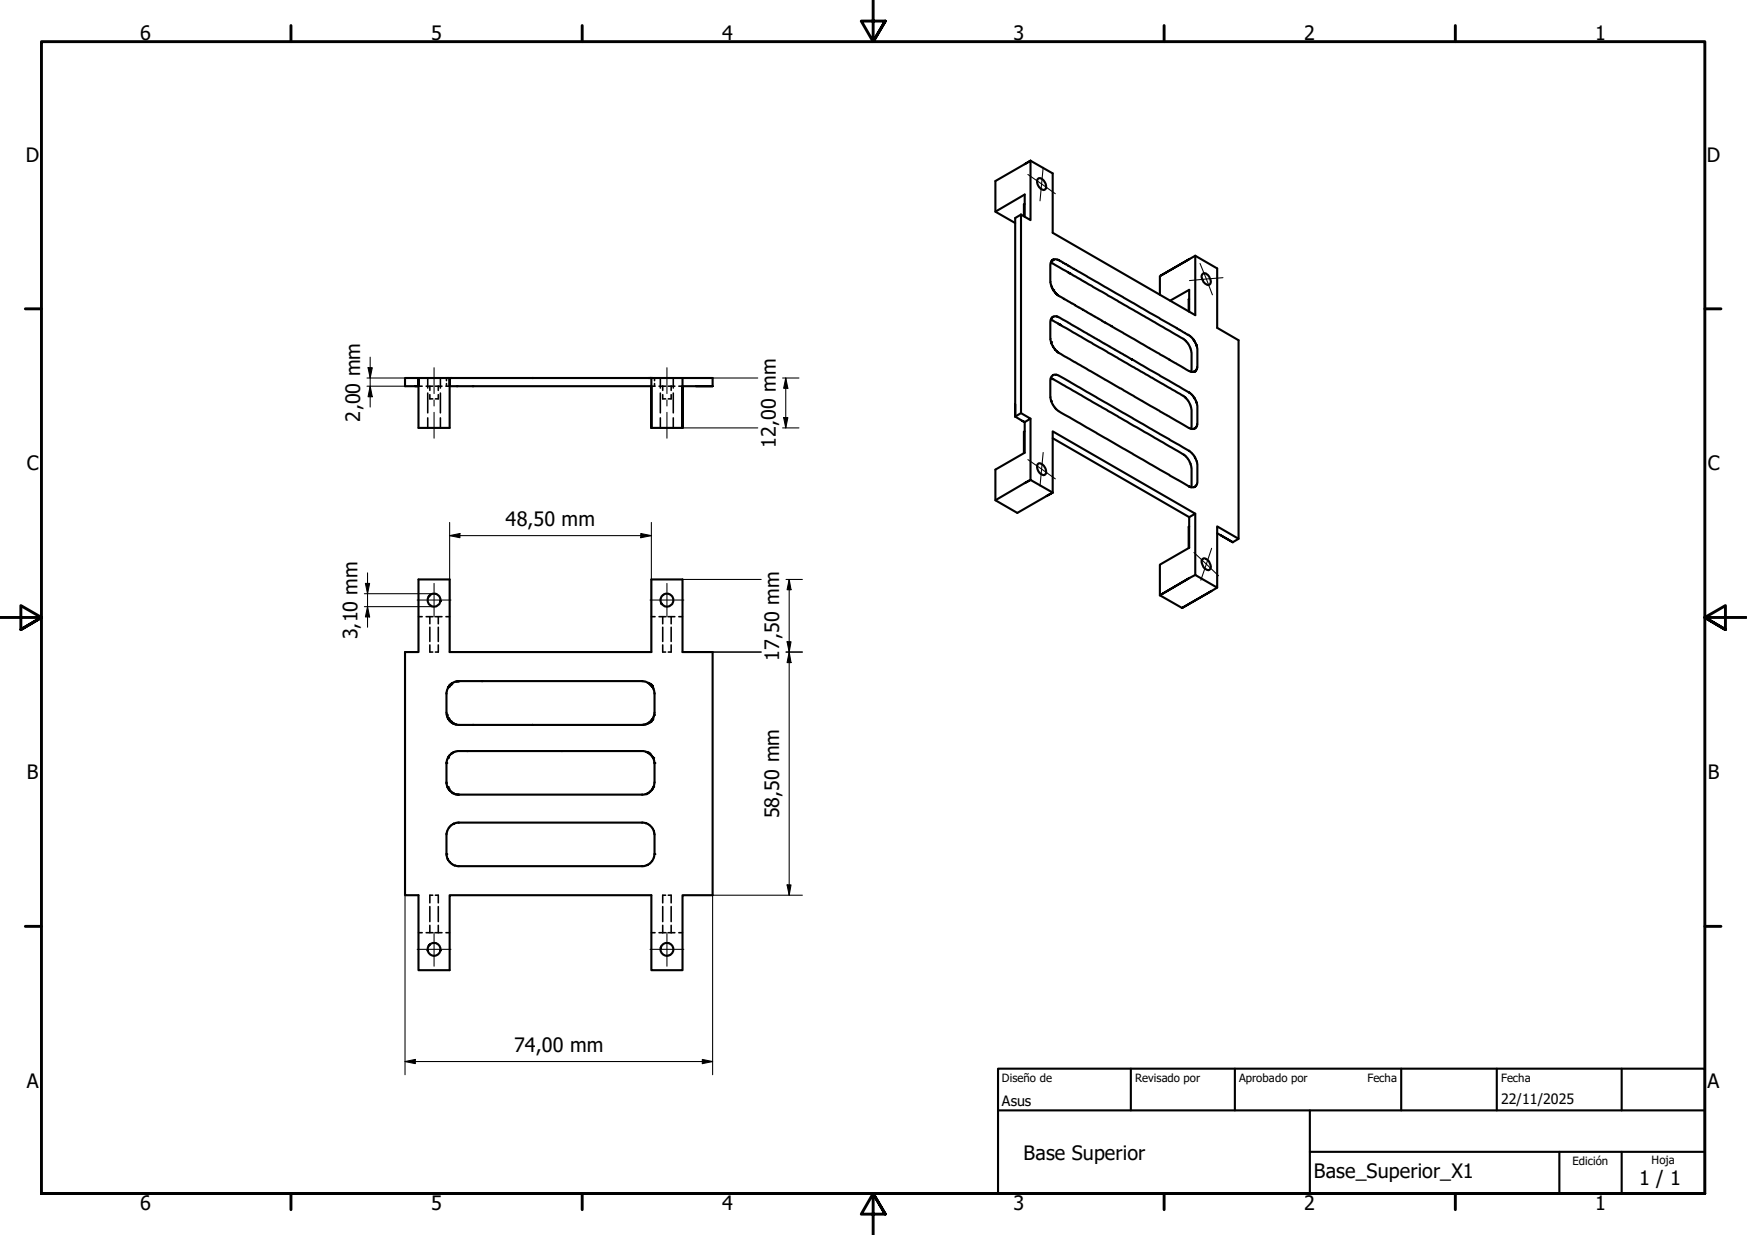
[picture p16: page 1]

Diseño de Asus | Revisado por | Aprobado por Fecha | Fecha 22/11/2025

Base Superior

Base_Superior_X1 | Edición | Hoja 1 / 1

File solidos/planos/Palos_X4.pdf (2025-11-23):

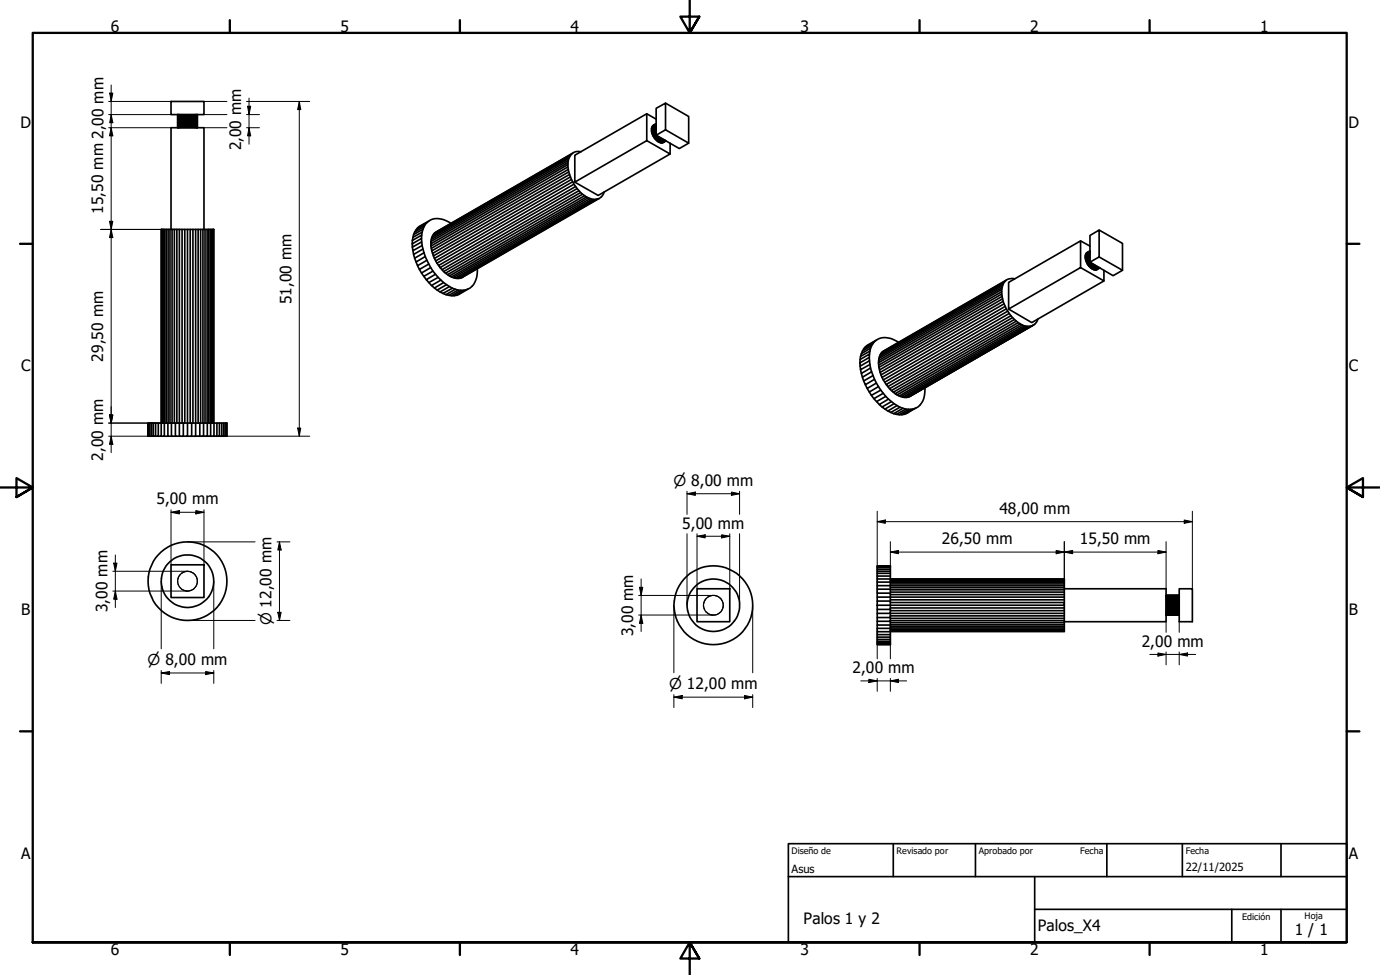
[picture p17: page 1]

P alo s 1 y 2

P alo s _ X 4 | E d i c i ó n | H oj a 1 / 1

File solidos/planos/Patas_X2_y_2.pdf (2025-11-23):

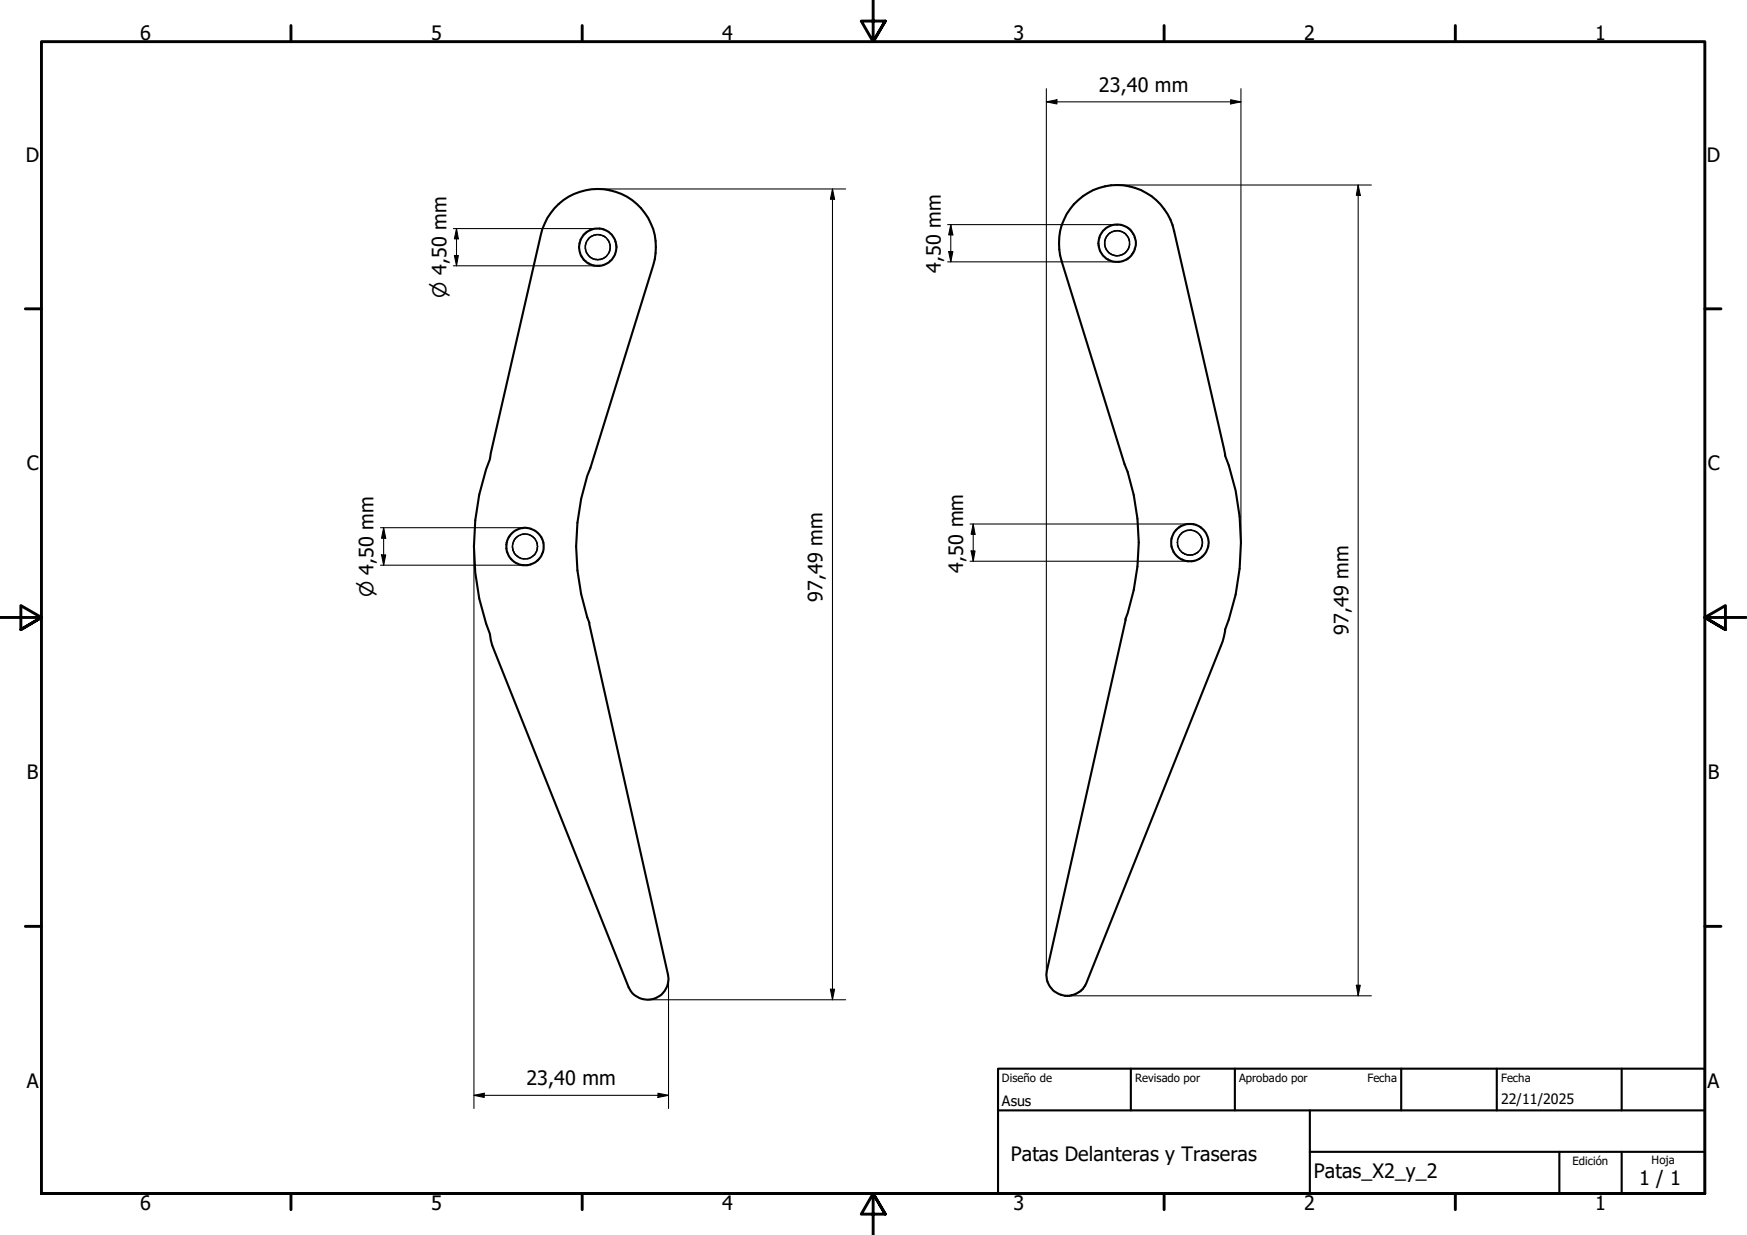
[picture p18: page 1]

Diseño de Asus | Revisado por | Aprobado por Fecha | Fecha 22/11/2025

Patas Delanteras y Traseras

Patas_X2_y_2 | Edición | Hoja 1 / 1

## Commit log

2025-11-20 solid archives
    [Accesorios_X2.SLDPRT, Base_Derecha_X1.SLDPRT, Base_Inferior_X1.SLDPRT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]
2025-11-23 Modelos3d y planos
    [Accesorios_X2.ipt, Accesorios_X2__2.ipt, Accesorios_X2__3.ipt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]
